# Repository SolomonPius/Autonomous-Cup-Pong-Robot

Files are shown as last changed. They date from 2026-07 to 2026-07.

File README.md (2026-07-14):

# Autonomous Cup Pong Robot

An autonomous turret robot that detects, aims at, and launches ping-pong balls into cups — built for MIE438 (Embedded Systems) at the University of Toronto.

**[Demo Video](https://www.youtube.com/watch?v=Q0vxaehKVus)**

Built by Solomon Pius, Abanoub Bashara, Roy Bou Abboud, and Yiyi Xu.

---

## Overview

The robot follows a sense-plan-act architecture: a rotating 1D LiDAR (TF-Luna) scans the playing field to find the closest cup, the ESP32 computes the required turret angle, and a servo-actuated turret aims and fires a ping-pong ball using dual flywheel motors and a feeder mechanism.

The project began as a full computer-vision-based aiming system (see [Project Proposal](docs/process/MIE438_Project_Proposal.pdf)) but was scoped down mid-project to a single-board, LiDAR-based design to fit the course timeline while preserving the core sense-plan-act architecture — full reasoning in the [Final Report](docs/process/MIE438_Final_Report.pdf).

**Final performance:**
- 100% cup detection rate
- ±2° angular accuracy
- Reliable shooting range up to 200cm

---

## Features

- **Perception:** TF-Luna LiDAR mounted co-axially with the turret barrel, scanning 5°–120° in 2° increments over I²C (400kHz) to find the minimum distance to a cup.
- **Aiming:** MG995 servo turret, slewed at a controlled max rate (2°/25ms) to avoid structural torque/instability.
- **Launch:** Dual brushless flywheel motors (L298N driver, 1kHz PWM) ramped to a fixed RPM, paired with a feeder motor (BTS7960 driver, 20kHz PWM) to advance the ball into the launcher.
- **Control:** Single ESP32-Wroom-32E running Arduino Framework C++ (PlatformIO), using a state machine (Scan → Aim → Fire → Done) to sequence the shooting cycle.
- **Custom hardware:** Fully custom 3D-printed mechanical structure, including a self-designed lazy susan bearing for turret rotation.

---

## System Architecture

```
[TF-Luna LiDAR] --I2C--> [ESP32] --PWM--> [Servo Turret]
                             |
                             +--PWM--> [Flywheel Motors (L298N)]
                             |
                             +--PWM--> [Feeder Motor (BTS7960)]
```

Full pinout and subsystem table in [docs/electrical/](docs/electrical/).

---

## Repo Structure

```
├── firmware/
│   ├── src/main.cpp          # Main control loop & state machine
│   └── tests/                # Per-peripheral bring-up test programs
│       ├── tfluna/
│       ├── servo/
│       ├── radar_scan/
│       ├── l298n/
│       ├── flywheel/
│       ├── hall_sensor/
│       ├── ir_beam/
│       └── all_motors/
│   └── tools/
│       └── radar_view.py     # Python visualizer for LiDAR polar scan
├── docs/
│   ├── electrical/            # Schematic, BOM, pinout diagram
│   ├── mechanical/             # CAD assembly, final assembly photos
│   ├── software/                # Architecture diagram, firmware flowchart
│   └── process/                  # Proposal, final report, performance metrics, instructor feedback
└── README.md
```

---

## Hardware

| Subsystem | Device | ESP32 Pin(s) | Protocol |
|---|---|---|---|
| LiDAR | TF-Luna (0x10) | SDA=GPIO21, SCL=GPIO22 | I²C @ 400kHz |
| Turret | MG995 servo | GPIO4 | 50Hz PWM (ESP32Servo) |
| Flywheel A | L298N EN_A/IN1/IN2 | 13/14/16 | 1kHz PWM (LEDC ch 8) |
| Flywheel B | L298N EN_B/IN3/IN4 | 27/17/23 | 1kHz PWM (LEDC ch 9) |
| Indexer | BTS7960 RPWM/LPWM/R_EN/L_EN | 18/19/25/26 | 20kHz PWM (LEDC ch 10) |

Power: 12V LiPo for motors, LM2596 buck converter to 5V for servo/LiDAR, 3.3V from ESP32 for remaining components.

**Note:** The ball feeder tube CAD was sourced from [Tylr-J42/XRP-Ping-Pong-Ball-Shooter](https://github.com/Tylr-J42/XRP-Ping-Pong-Ball-Shooter) and is not original work — all other mechanical parts were custom-designed in Onshape.

### CAD Files
 
- **Live/editable:** [Onshape Document](https://cad.onshape.com/documents/006694550e54c6535ae3a296/w/fde7019724d253a4cde574ab/e/71389e919a5da7285be2d17a) — full feature tree, editable, always reflects the latest version.
- **Static/portable:** [Final_CAD_Assembly](docs/mechanical/Final_CAD_Assembly.step) — exported STEP file, viewable in any CAD tool, kept as a backup in case the Onshape link ever changes or becomes inaccessible.
---

## Testing & Validation

Each peripheral was bring-up tested independently before full integration (see `firmware/tests/`):
- `tfluna` — I²C bring-up and distance accuracy
- `servo` — end-to-end MG995 sweep
- `radar_scan` — combined servo + LiDAR polar scan (visualized via `radar_view.py`)
- `l298n` / `flywheel` — flywheel driver activation
- `all_motors` — full firing sequence, end-to-end

---

## Known Limitations & Future Work

- Flywheel motors run at a fixed shared duty cycle — a closed-loop RPM control system (hall-effect sensor + PID) was designed but not completed due to hardware issues.
- The custom-printed turret bearing introduced some tilt/instability during rotation.
- An IR beam sensor for shot-state detection was attempted but never worked reliably in testing.
- Planned upgrades: 2D LiDAR (replacing the rotating scan), full autonomy-stack state machine, working IR beam integration.

Full reflection in the [Final Report](docs/process/MIE438_Final_Report.pdf).

---

## AI Usage Disclosure

In accordance with course guidelines: Claude and Claude Code were used for generating/refining inline code comments and documentation, and for debugging assistance (peripheral bring-up issues, sensor behavior interpretation). All architectural decisions, hardware design, firmware logic, and testing were performed by the team.

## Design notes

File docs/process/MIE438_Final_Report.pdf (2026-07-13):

# MIE438 Project Report: Autonomous Cup Pong Robot

### April 7, 2026

### Abanoub Bashara (1010010612) Solomon Pius (1009975127) Roy Bou Abboud (1009905462) Yiyi Xu (1009851402)

### Demo link: https://www.youtube.com/watch?v=Q0vxaehKVus

# Introduction & Project Evolution

The original project proposal outlined a five-phase plan to develop an autonomous cup pong robot capable of playing a perfect game without human intervention. Phases three to five focused on computer vision (CV) and user interface (UI) design. After receiving feedback on our proposal, we made the decision to eliminate the computer vision subsystem from the scope (see docs/process/Instructor_Feedback.md). The primary concern was integration complexity as well as course relevance. Developing a reliable vision pipeline and integrating it with a real-time embedded control stack introduced many points of failure and was far out of scope for this course’s content.

Instead of CV, we decided to use a 1D LiDAR (TF-Luna), which provides direct distance measurement to the cups. By mounting the LiDAR on the rotating base, we are able to scan the entire playing field. This pivot allowed us to preserve the core sense-plan-act architecture of the robot while also allowing the team to focus on the embedded problems: sensor integration, motor power & control, and communication protocols.

The revised project scope targets completion of Phase 1 (MVP – repeatable ball launch at fixed distance) and Phase 2 (LiDAR-enabled autonomous aiming and launch at a fixed distance). The final turret robot boasts a servo-actuated base to scan the playing field and aim the turret, a LiDAR subsystem that finds the closest cup using minimum distance, dual brushless motors that spin flywheels to a set RPM, and a feeder motor to push the ball into the launcher.

# Final System Architecture

The final system uses only a single ESP32 development board to consolidate all computation and real-time control (see docs/electrical/ESP32_Pinout_Diagram.pdf). This is a significant simplification from the original dual-platform architecture (Raspberry Pi + ESP32), which was proposed in the initial design. The elimination of CV also removed the need for a high-compute platform entirely. This also helped tighten integration between sensing and actuation since every signal is either generated or consumed directly by the ESP32. The final architecture follows a sense-plan-act paradigm (see docs/software/Software_Architecture.png and docs/software/Firmware_Flowchart.png).

For sensing, the TF-Luna sensor is mounted co-axially with the turret barrel to measure the cup distances and communicate with the ESP32 over I

2C (see firmware/src/main.cpp, line 123). After powering on the system, the robot begins by sweeping across 5 to 120 degrees of the playing field (and back) in 2-degree increments and logging the smallest measured distance. Each step is delayed by 120ms to gather a reading, and the communication over I

2C occurs at a very fast 400kHz frequency to ensure minimal latency. After an entire scan, the minimal distance to a cup and the angle at which it was found is passed as an input to other subsystems.

Next, the current version of our robot requires minimal planning. We had planned for a system that would use a full projectile model or interpolate distances to calculate the PWM (and hence speed) to reach a given cup, this could not be implemented due to faulty hardware. This would be a large improvement in future iterations if undertaken. Instead, the robot plans a servo rotation to the angle that recorded the shortest cup distance, and uses a fixed PWM for every shot (meaning shot distance was fixed as well) (see firmware/src/main.cpp, line 171-232).

For actuation, the ESP32 then commands the servo to slowly slew towards the selected angle at a max of 2 degrees per 25ms to avoid sudden movements (see firmware/src/main.cpp, line 137). This was needed as writing the angle to the servo directly would create a large torque, which could damage the structure or cause instability. After reaching the given angle, the ESP32 pushes PWM signals, which gradually increase into the flywheel motors via a L298N motor driver until the set value is reached. The flywheels first receive a PWM of 120/255 duty for 300ms to overcome the heavy load from the wheels and begin spinning. Then, the duty is dropped to 42/255 for 6 seconds to allow a proper spin-up, which is followed by a 150/255 duty to the feeder motor, which advances the ball into the launcher (see firmware/src/main.cpp, line 235-292).

Beyond that, the system is powered using a 12V LiPo battery for the motors, an LM2596 buck converter providing 5V to the servo & other peripherals, and the standard 3.3V output from the ESP32 for the remaining components.

# Hardware Design

The 3D printed subsystem can be found in docs/mechanical/Final_CAD_Assembly.obj. This shows the final assembly of our 3D printed parts. From the final assembly document, the ball feeder tube was the only part not designed by us. It was taken from a GitHub repository created by Tylr-J42 https://github.com/Tylr-J42/XRP-Ping-Pong-Ball-Shooter. The used file can be found in Ping Pong Ball Shooter v29.step. All other parts of the CAD were created using Onshape.

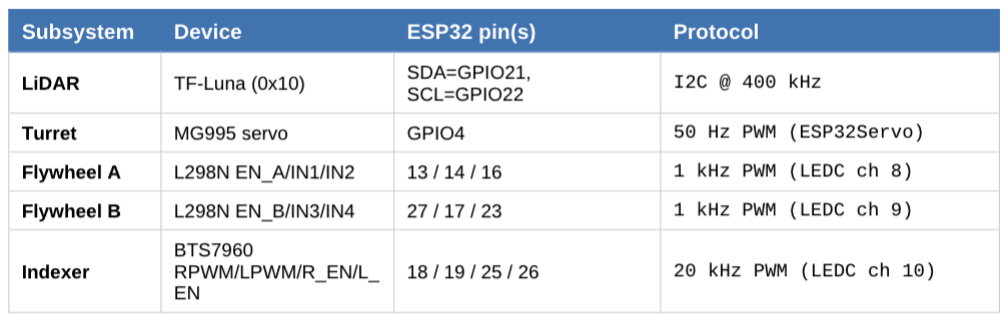
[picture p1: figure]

Table 1: Hardware Subsystem and ESP32 Connections

The core compute system is the ESP32-Wroom-32E running Arduino Framework C++ compiled through PlatformIO. Power is supplied from a 12V battery pack with a separate regulated 5V for the servo and TF-Luna, and 12V for the motor drivers.

The flywheels share the L298N and run at the same duty; we were not able to complete an RPM sensor and variable control system (see Reflection / Conclusion section) to address this. The BTS7960 drives the indexer because it has significantly higher current headroom for the stall current during ball-push. Running the indexer to 20 kHz kept the motor out of the audible whine range, while the L298N flywheels run at 1 kHz, which the L298N’s slower switching tolerates well.

A system schematic and full BOM are in docs/electrical/.

# Firmware Design

All firmware can be found in firmware/. The PlatformIO project also defines one bring-up environment per peripheral: TF-Luna, IR beam, hall sensor, limit switches, flywheel, servo, and indexing motor. Each is compiling a single test file in firmware/tests. These programs were how we validated each subsystem before integration, and they remain the authoritative reference for each peripheral’s wiring.

A firmware flowchart can be found in docs/software/Firmware_Flowchart.png

Use of ESP32 Peripherals
Course-relevant microcontroller features used:
- • I

2C (Wire) at 400 kHz, reading six bytes from TF-Luna register 0x00 per sample and extracting a little-endian 16-bit distance.
- • LEDC (ledcSetup / ledcAttachPin / ledcWrite) for three independent hardware PWM
- channels at different frequencies, the only way to run the BTS7960 at 20 kHz and the L298N at 1 kHz simultaneously without software-PWM jitter.
- • ESP32Servo (Arduino library on top of LEDC) for 50 Hz RC servo pulses at 500–2500 μs.
- • USB serial at 115 200 baud as both a human-readable log and a machine-readable CSV
- stream for offline polar plotting.

Libraries Used:
All developer-supplied libraries (Arduino core for ESP32, Wire, LEDC) are part of the Espressif Arduino framework, and per the course guidelines, do not require citation.
Third-party library: ESP32Servo - Kevin Harrington, John K. Bennett. https://github.com/madhephaestus/ESP32Servo

# Testing & Results

Each peripheral was validated independently using the test environments in firmware. firmware/test/tfluna verified I

2C bring-up and distance accuracy; firmware/test/servo swept the MG995 end-to-end;firmware/test/radar_scan validated the combined servo + LiDAR polar scan. The LiDAR polar scan was visualized by taking the LiDAR outputs, streaming them through serial to a Python program that visualized the output (see firmware/tools/radar_view.py). The servo then returns to the minimum distance measured by the LiDAR; firmware/test/l298n and firmware/test/flywheel validated the flywheel driver activation; and firmware/test/all_motors validated the full firing sequence end-to-end.

End-to-end performance metrics (see docs/process/Performance_Metrics.pdf)

- Cup detection rate: 100%
- Angular accuracy: +/- 2 degrees
- Maximum reliable shooting distance: 200cm

# Course Content Connection

This project required many MIE438 concepts to complete on both the hardware and firmware sides. The ESP32 was selected due to its breadth of GPIO pins (see docs/electrical/ESP32_Pinout_Diagram.pdf), strong compatibility with hardware requiring both 3.3V and 5V, and its flexibility for integrating course concepts under one hood. All inputs, outputs, control signals and some powering were all coordinated through the ESP32.

In order for our robot to find the minimum distance from itself to a cup, we combined the I

2C protocol
with macros to create the cup detection subsystem. The I

2C communication protocol was set up between the ESP32 and TF-Luna LiDAR, simplifying the transfer of data significantly and ensuring consistent readings for the robot to aim itself properly. A macro was used to combine two 8-bit (1 byte) signals read over I

2C into a single 16-bit value to quickly construct the signal needed for the robot to choose the best shooting angle (see firmware/src/main.cpp, line 39). Similarly, inline functions were used for actions that were repeated multiple times and required quicker execution, such as setting the duty cycle for the flywheel or stopping all the motors at once (see firmware/src/main.cpp, line 107-118).

Additionally, the concept of pulse-width-modulation (PWM) was used in conjunction with motor drivers to control the three motors on our system: 1) the two flywheel motors and 2) the feeder motor. Varying PWM was initially used as a testing strategy to qualitatively determine the range of values that yield a feasible launch distance of the ball (see docs/mechanical/Final_Assembly.png). Then, PWM signals were generated from the ESP32 and delivered to the appropriate motors via both our dual-channel motor drivers. This concept was important to our system, as we were building a control loop that used RPM readings to adjust PWM in order to eliminate any variance between both motors (however, this system was never implemented due to faulty hardware).

Furthermore, we made use of a state machine to encode the robot’s different stages during a shooting cycle. The three states were Scan, Aim, Fire, and Done. This greatly helped our system by breaking down phases within the sense-plan-act paradigm and allowing for easy debugging and readability. For example, timing the flywheel and feeder motors with the servo was much easier once we implemented a state machine that distinguishes between both phases (see firmware/src/main.cpp, line 235-292).

Finally, two additional PID controllers were planned for the system and would be the next improvements that incorporate course concepts. The first one would be a DIY RPM sensor using a magnet and hall effect sensor on the flywheel (see firmware/tests/hall_sensor/main.cpp). This system would take in RPM, use a precalculated “RPM vs Distance Travelled by Ball” chart to determine a PWM value for a required cup distance, and adjust accordingly using a tuned PID controller. Similarly, the built-in encoders of the feeder motor would be fed as an input to a second tuned PID, which would control the total rotation of the feeder, increasing consistency between shots.

# Reflection & Conclusion

The two most consequential engineering design decisions we made for this project were the pivot away from computer vision and the consolidation to a single ESP32 platform. We believe both decisions were correct. Eliminating the CV pipeline allowed us to focus on the actual embedded systems work, such as sensor integration, hardware assembly, design testing, and firmware architecture. The TF-Luna was a clean replacement that fit naturally with the ESP32 stack over I

2C.

The most significant issues we encountered that limited our robot’s capabilities were all related to mechanical or hardware rather than firmware. Firstly, the custom ball bearing we created for the rotating base caused turret tilting and, at times, instability during rotation (see docs/mechanical/Final_Assembly.png), creating a launch error that could never be reduced. Secondly, only 1 out of 2 hall sensors was proven to be effective, and there was no structurally sound way of attaching the neoprene magnets to the flywheel at high RPMs, hence abandoning the PID-controlled PWM for the motors was required. Thirdly, the infrared beam sensor we wanted to implement on the robot to determine the current state of the ball launch never worked during testing, and was therefore removed from the system (see firmware/tests/ir_beam/main.cpp). Finally, the PID-controlled feeder motor was also never implemented due to hardware issues related to its wiring, which unfortunately meant no physical control loops within our system. In the future, fixing these issues would be the biggest way of improving the robot’s performance considerably. Beyond that, other upgrades that would strengthen our robot include using a 2D lidar as opposed to the servo spinning base, implementing a fully-fledged state machine for the entire autonomy stack, or successfully fitting an infrared beam to detect when the ball is launched.

In conclusion, we worked around our original ambitious goal and created a successful embedded system centred around a single ESP32 that correctly shot ping-pong balls into cups.

# AI Usage Statement

In accordance with course guidelines, we disclose the use of AI tools during this project. Anthropic's Claude and Claude Code were used in two limited capacities: generating and refining inline code comments and documentation within the firmware source files, and assisting with debugging after firmware development, including diagnosing peripheral bring-up issues and interpreting unexpected sensor behaviour. All architectural decisions, hardware design, firmware logic, and testing were performed by the team. AI-generated suggestions were reviewed, validated, and modified by team members before being incorporated into the final codebase.

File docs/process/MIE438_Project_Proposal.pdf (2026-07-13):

## MIE438 Project Proposal: Autonomous Cup Pong Robot

### January 19, 2026

### Abanoub Bashara (1010010612) Solomon Pius (1009975127) Roy Bou Abboud (1009905462) Yiyi Xu (1009851402)

1. Problem Overview & Solution Scope 1.1 Proposed Project Timeline
2. High-Level System Overview
2.1 Overall System Architecture
2.2 Perception Subsystem
2.3 Computational & Control Subsystem 2.4 Actuation Subsystem
3. Hardware (Mechanical / Electrical) Details
4. Software / Controls / UI Details
5. Conclusion

## 1. Problem Overview & Solution Scope

Cup Pong (otherwise known as Beer Pong) is a social game consisting of two teams taking turns throwing a ping pong ball into the opposition’s cups. Ten cups are placed on both ends of the table, typically in a pyramid formation, with teams standing behind their respective set of cups. Each team, composed of 1-2 players, receives two attempts at sinking a ping pong ball across the table before the turns switch. If a ball is sunk into a cup, that cup is removed from the game, and in order to win, a team must sink a ball into all the opposition's cups. Additionally, if a team sinks both of their shots within an attempt (ie. they didn’t miss), they receive an additional two shots as a reward, known as balls back, with no limit to how many times this can be done. Hence, if a team receives balls back and continually hits their two shots, they can win the game in a single turn, known as a perfect game.

The objective of our project is to develop an Autonomous Cup Pong Robot capable of playing a perfect game without human intervention. An overview of the robot’s capabilities includes:
1. Detecting cup geometry and distance from one end of the table
2. Pivoting its launcher in the direction of a desired cup
3. Calculating the required launch speed of the ping pong ball
4. Launching the ball and sinking it into a cup
5. Repeating steps 1-4 until the robot achieves a perfect game

Many game mechanics are beyond the scope of the robot yet still crucial to the game’s playability. Human interaction to ensure a smooth game is required in the following ways:
- The robot’s storage tank must be manually filled with ping pong balls
- Once a cup is eliminated, a human will remove the cup off the table
- After a shot, the robot should standby until it receives the green light from a human to shoot again. This can be phased out in improved designs
- If the robot misses, a human will manually place it in standby after its attempt

### 1.1 Proposed Project Timeline

Phase 1: Minimum Viable Product (MVP)
A single cup is placed at a fixed, known distance directly in front of the robot. This phase will verify that the core turret and launching mechanisms work. This phase will be considered complete once the system can demonstrate repeatable ball release with controllable velocity and consistent projectile motion.

Phase 2: Controlled Autonomy
Again, a single cup is placed, but now at a random location on the table. The coordinates will be manually provided to the robot. The robot autonomously rotates its base to align with the target and computes the required launch speed to successfully sink the ball. This phase must demonstrate closed-loop control over aiming and velocity.

Phase 3: Vision-Based Target Detection
Again, a single cup is placed at a random location on the table. The robot must now use its camera-based perception to detect the position of the cup and extract the coordinates in order to aim and sink the ball.

Phase 4: Full Game Automation (Perfect Game)
The robot sequentially targets and eliminates all cups on the table, with the only human intervention being cup removal and ball reloading. This phase is complete once the fully autonomous pipeline can consistently win perfect games.

Phase 5: User Experience & Taunting
This phase adds a simple interface to switch between manual cup selection and fully autonomous gameplay. Optionally, audio and/or visual taunting may be implemented.

## 2. High-Level System Overview

The robot is designed in a modular manner, as demonstrated in the distinct phases outlined in section
1.1. At a high level, the system follows a sense-plan-act architecture: visual information about the environment is processed to determine target locations, a ball trajectory is computed, and the mechanical subsystems execute the shot.

### 2.1 Overall System Architecture

The system is composed of three interacting subsystems (see figure 1 in the appendix):
1. Perception Subsystem (Phase 3+): identifies cup locations on the table
2. Computation & Control Subsystem (Phase 2+): computes aiming and launch parameters
3. Actuation Subsystem (Phase 1+): physically loads, aims, and launches the ball
This separation allows for the development and testing of subsystems before full system integration.

### 2.2 Perception Subsystem

A camera is mounted on a stationary base on top of the robot and captures a 2D image of the playing field. This image is processed by computer vision algorithms to detect cup geometry and estimate the coordinates of each cup relative to the robot. These algorithms will either run on an external remote laptop or a Raspberry Pi to decouple from time-sensitive computation (next section). We also suspect that a dual-chip board such as the Arduino Uno Q might be of use in this application.

### 2.3 Computational & Control Subsystem

Based on the coordinates, this system computes the required turret rotation angle and launch speed using projectile motion models. A low-level language (e.g., C++) running on an ESP-based microcontroller or similar executes real-time control tasks, including motor commands, timing and sequencing.

### 2.4 Actuation Subsystem

This system consists of a Nerf-style motorized launcher to provide ball velocity, a secondary actuator (servo or solenoid) for ball loading, and a rotating base or turret for horizontal aiming. The motorized launchers spin two flywheels at a set speed to launch the ball. Upon receiving control commands, the robot aligns itself with the target, adjusts launcher speed, feeds a ball, and fires.

## 3. Hardware (Mechanical / Electrical) Details

### 3.1 Hardware Overview

The design features a fixed base with a camera attached via a vertical mast; the shooter is mounted on top of the base and rotates the turret independently of the base (See figure 2 in the appendix). Upon activation, a fixed camera takes a picture of the cup field (assuming standard camera placement and lighting). The compute unit then processes the frame to find cup coordinates and calculates the required turret angle and flywheel RPM to reach the target cup. These metrics are then fed to the embedded controller, which rotates the turret, ramps the flywheel to the command RPM and activates the loader to feed a ball into the spinning wheels for launch.

### 3.2 Actuation + Mechanical Design

The system utilizes 3 actuators. (1) Two Nerf-style motors that spin flywheels to a given RPM for launch. (2) a turret motor to rotate the shooter heading, (3) a feeder motor driving a pinion mechanism to push one ball at a time into the spinning flywheel. The flywheel RPM will be controlled by varying motor drive power, while the turret and feeder move at a slow, consistent rate to avoid structural stress. The vertical shooting angle of the turret will be fixed at 50-60 degrees, striking a good balance between maximizing shot distance and ball height as well as minimizing drag.

### 3.3 Sensors + I/O Requirements

The system's primary sensor is a mounted camera that captures an image on user command. That image is then processed on a Raspberry Pi or remote Laptop and outputs setpoints to the MCU over USB serial (Target turret angle & Flywheel RPM). Table 1 in the appendix shows estimates on the quantitative I/O analysis.

### 3.4 Compute + Embedded Platform

The system uses a Raspberry Pi 4 Model B or Remote PC for camera capture, vision, trajectory/RPM/angle calculation and an ESP32 for real-time actuation (turret servo control, flywheel RPM command generation, feeder sequencing and standby logic). Since the ESP32 is 3.3V logic, if any hardware requires 5V signalling, level shifting may be required. Power will come from a wall adapter with separate regulated rails for logic, 5V for Pi, 3.3V for ESP32, and motors as required.

### 3.5 Power + Key Components/BOM

The system will be powered via a wall adapter that steps down to the required rails for the ESP32, servos, and flywheel motors. Safety hardware will include a power switch plus fuse, and a fuse holder in line with the supply. Current BOM can be found in the appendix.

## 4. Software / Controls / UI Details

The software required for this project goes beyond the scope of this course, but we believe proper implementation is needed to manifest our vision of what a fully autonomous cup pong robot should achieve.

### 4.1 Vision

As mentioned before, the software is responsible for producing control commands for where the shooter needs to aim. We first need to pre-process the image by removing the tilt effect from the camera, and then extracting the location of the cups. To achieve this, there are 2 methods we can explore. The first method is using existing libraries for computer vision, such as OpenCV/cv2 in Python, and using least squares regression to fit circles on the rims of the cups. The center of the circles should be the coordinate of the cup and thus the shooter should aim there. A technique that can make this approach more effective is to apply some sort of retroreflective paint to the rim of the cups, and using a camera that can pick up said retroreflective paint. An alternative method, which might yield better results, is to manually train our own vision model on labelled data of images of shots. This will be more tedious to do but might yield better results if we are unable to fit OpenCV in our use case.

### 4.2 Controls

Once the coordinates of the cups are determined, we can select 1 cup to shoot at first. There are again 2 ways to convert coordinates to turret angle and shooter RPM. We can either solve for them analytically using inverse kinematics, which in theory should work 100% of the time. However, under real conditions with non-negligible drag and spin on the ping pong balls, idealized assumptions might not hold up. A different method is to manually find pivot angle + shooter RPM combos by testing different shots, and then interpolating those points for all the cup locations.

The turret motor should have an encoder, so we’re able to use a closed loop control such as PID to get it to its desired location. For the flywheel motors, we can use an RPM sensor to achieve closed loop speed control, with the control input being the PWM duty cycle. For any known target distance, the system determines a desired motor RPM, and the PWM signals are adjusted using the RPM sensor to achieve this desired value before the ball is launched.

### 4.3 UI

There needs to be some way for us to interact with the robot once it starts playing the game. Most likely we will have a simple push button to allow the robot to start shooting once it's been reloaded and between shots.

If the robot is able to consistently win games, we can add an LCD display to personify the robot and add a competitive flair. It can taunt the enemy when it makes shots and emote as its shooting. Alternatively it can be used as a status light, showing us what state the robot is in (spinning up shooter, aiming, processing, etc).

## 5. Conclusion

Overall, we believe this embedded system design is feasible under the scope of this course and we are highly interested in pursuing this project. We consider achieving Phase 2 (Controlled Autonomy) a complete embedded systems project, with subsequent phases adding additional functionalities that greatly increase the system’s performance. It is important to note that 3D printed structural and mechanical components such as the base, gears, etc are not part of the embedded systems design work we are planning to pursue, and hence, we will be using pre-existing models found on the internet. Additionally, we plan on always testing and demonstrating our system in stable environments with good lighting, mitigating unintended factors (e.g. occlusions) that may decrease the robot’s performance. Finally, in terms of teaching team feedback, what would help us the most is insight on whether using a Raspberry Pi, Arduino Uno Q, or remote PC as a replacement or in combination with an ESP32 DevBoard are admissible options for the course and this project.

## 6. Appendix

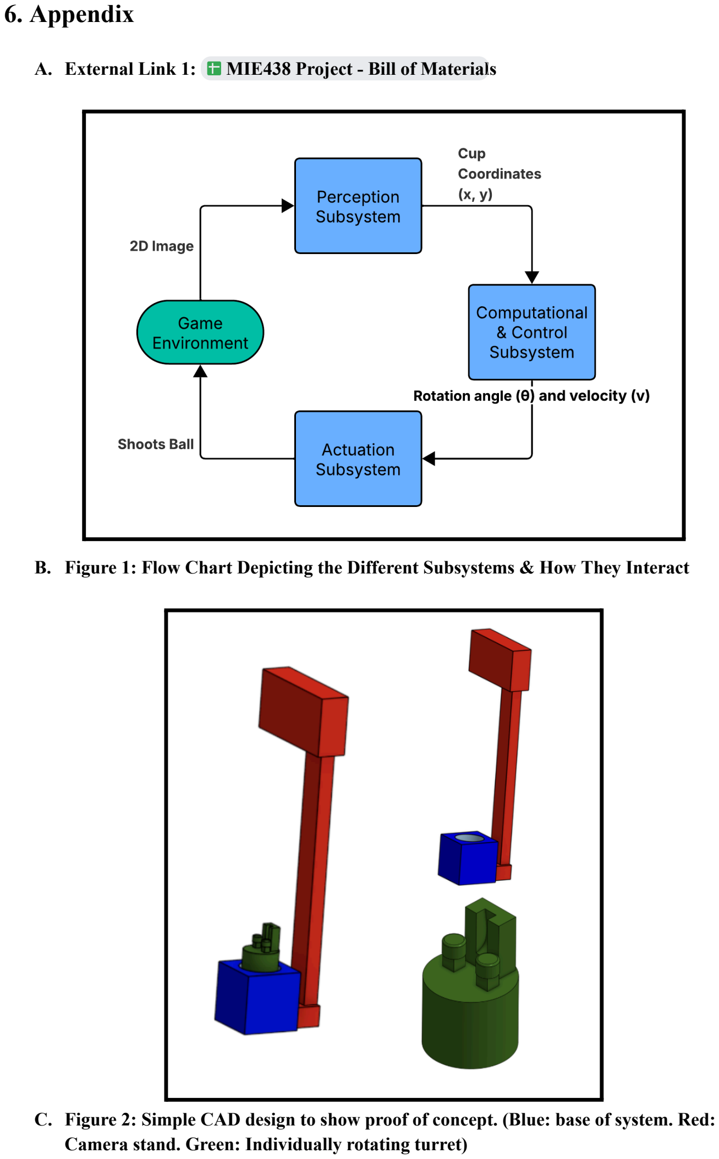
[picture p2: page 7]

A. External Link 1: MIE438 Project - Bill of Materials (https://docs.google.com/spreadsheets/d/1_pdvrkftF5BO4UQJaOoq0thF5PodlNcQAFAqRodngs0/edit?gid=0#gid=0)
B. Figure 1: Flow Chart Depicting the Different Subsystems & How They Interact
C. Figure 2: Simple CAD design to show proof of concept. (Blue: base of system. Red: Camera stand. Green: Individually rotating turret)

Signal | Type | Where | Estimated range/requirement
Camera frame | USB/CSI video | Pi | 1280×720 (or 640×480) single-frame capture; needs consistent lighting for detection
User ‘shoot’ trigger | Digital GPIO | Pi | Button input (0/1), debounced (~20–50 ms)
Turret angle (tracked) | Software state | MCU | 0–180° (or ±90°), updated from last command; resolution target ~1–2°
Setpoints (angle, RPM, fire) | USB serial | Pi → MCU | ~5–10 Hz command updates; target end-to-end latency < ~250 ms
Flywheel command | PWM(to motor driver) | MCU → driver | RPM setpoint ~0–20,000 RPM (estimate), resolution ~100–250 RPM
Turret motor command | Step/Dir or PWM | MCU → driver | Slow slew target ~10–30 °/s (estimate)
Feeder command | PWM + dir (or timed on/off | MCU → driver | One-ball feed cycle ~0.5–1.5 s (estimate), return-to-zero after shot
D. Table 1: Hardware I/O Map

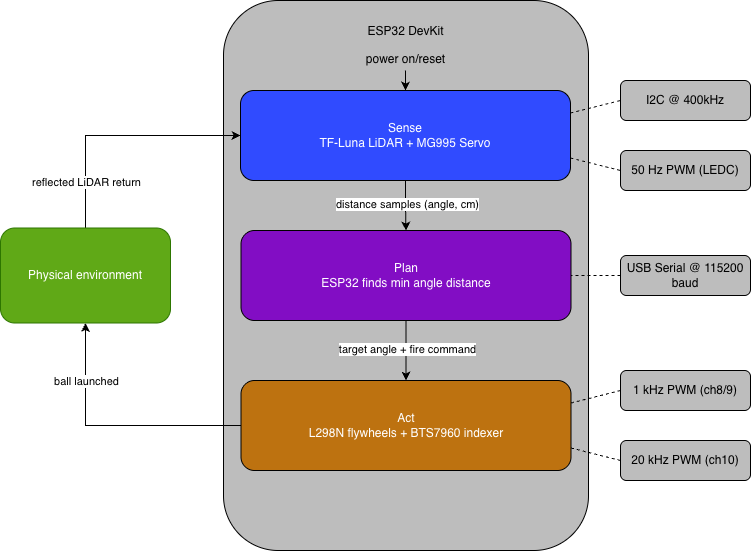
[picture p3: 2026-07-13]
docs/software/System_Architecture.png

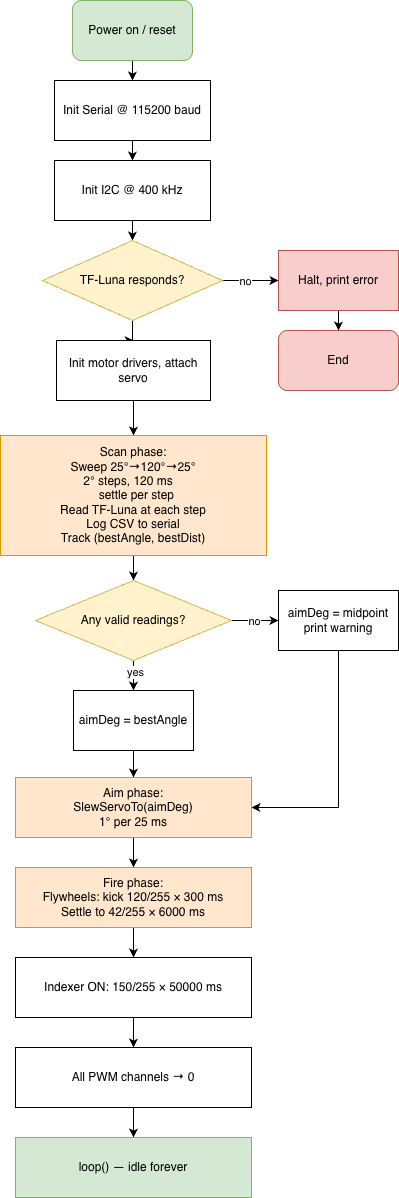
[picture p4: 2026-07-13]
docs/software/Firmware_Flowchart.png

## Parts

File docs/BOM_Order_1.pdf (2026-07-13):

Final List:
- 2x Flywheel motors
- 775 Brushed DC Motors
- https://www.amazon.ca/dp/B0BB2V8PNK/ref=olp-opf-redir?aod=1
- 1x Base motor
- 130 RPM Motor (Loaned)
- 1x Servo - Rack & Pinion Ball Feeder
- MG995 Servo (Loaned)
- 3x Motor Drivers OR 1x Dual + 1x Single Motor Drivers
- DRV8825PWP Single
- https://www.digikey.ca/en/products/detail/texas-instruments/DRV8825PWP/2676775 (https://www.digikey.ca/en/products/detail/texas-instruments/DRV8825PWP/2676775)
- TB6612FNG,C,8,EL
- https://www.digikey.ca/en/products/detail/toshiba-semiconductor-and-storage/TB6612FNG-C-8-EL/1730070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 4iAugL5A (https://www.digikey.ca/en/products/detail/toshiba-semiconductor-and-storage/TB6612FNG-C-8-EL/1730070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)
- 1x Infrared Sensor - Ball Detection
- https://www.mouser.ca/new/dfrobot/dfrobot-sen0503-ir-break-beam-sensor/
- 1x Lidar Sensor
- TF-Luna (Loaned)
- 1x Ultrasonic Sensor
- HC-SR04 (Loaned)
- 1x Power Switch (Rocker)
- https://www.digikey.ca/en/products/detail/e-switch/RA1113112R/3778055
- 1x Buck Converter
- https://www.digikey.ca/en/products/detail/texas-instruments/TPS51388VABR/25811453 (https://www.digikey.ca/en/products/detail/texas-instruments/TPS51388VABR/25811453)
- 1x Breakout Board
- https://www.digikey.ca/en/products/detail/adafruit-industries-llc/4090/9951930
- 2x Limit Switch
- https://www.digikey.ca/en/products/detail/e-switch/SS0750301F040P1A/2639 078 (https://www.digikey.ca/en/products/detail/e-switch/SS0750301F040P1A/2639078)
- 2x Hall Sensors
- https://www.digikey.ca/en/products/detail/infineon-technologies/TLE4906LHALA1/954435 (https://www.digikey.ca/en/products/detail/infineon-technologies/TLE4906LHALA1/954435)
- 4x Pushbuttons
- https://www.digikey.ca/en/products/detail/same-sky-formerly-cui-devices-/TS02-66-55-BK-160-LCR-D/15634374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 (https://www.digikey.ca/en/products/detail/same-sky-formerly-cui-devices-/TS02-66-55-BK-160-LCR-D/15634374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)
Misc:
- Jumper Wires
- Breadboard
- M3 Screw Kit (Loaned)
- Small Magnets (Roy)
- Push Button
- Lazy Susan Bearing

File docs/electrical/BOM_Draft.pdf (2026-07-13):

NOTE: Structural items will be 3D printed for cost and time effectiveness. This includes parts such as the structural body, gears, rack, etc. Items such as fasteners and screws for assembly are not included in this BOM.

COMPUTE & CONNECTION
ITEM | QUANTITY | COST (per unit) WEBSITE | NOTES
ESP32 DevKit V1 | 1 | 0$ | N/A | Provided by teaching team
OV2640 Camera Module | 1 | 1-25$ | TBD
Breadboard | 1 | 0$ | N/A | Easily rented
Jumper Wires + Connectors | As Needed | 0$ | N/A | Myfab scrab bin
Fuses + Fuse Holder | 1 | 1-5$ | TBD | Safety Precaution

ACTUATION & CONTROL
ITEM | QUANTITY | COST WEBSITE | NOTES
MG90S Servo | 2 | 1-10$ | TBD | 1 for pivoting base, 1 for driving pinion back and forth
Nerf Blaster Motors | 2 | 13-14$ | https://outofdarts.com/collections/motors-2019 | These motors would be ideal for speed, but other motors are also acceptable
Flywheels (Rubber) | 2 | 10-25$ | https://www.studica.ca/en/2inch-compliant-wheel-12-inch-hex-40-durometer-orange | Standard wheels may be used as an alternative
TB6612FNG (Dual) Motor Driver | 1 | 3-25$ | TBD
Buck Converter | 1 | 12-20$ | TBD | Step down input voltage from wall / laptop charger
Limit Switch | 1 | 1-3$ | TBD | Adds a reference to rack and pinion system
Power Switch | 1 | 1-2$ | TBD
RPM Sensor | 1 | 5-20$ | TBD | Closed looop control of flywheel speeds via PWM
INITIAL ESTIMATED COST (lower bound): | 48-149$

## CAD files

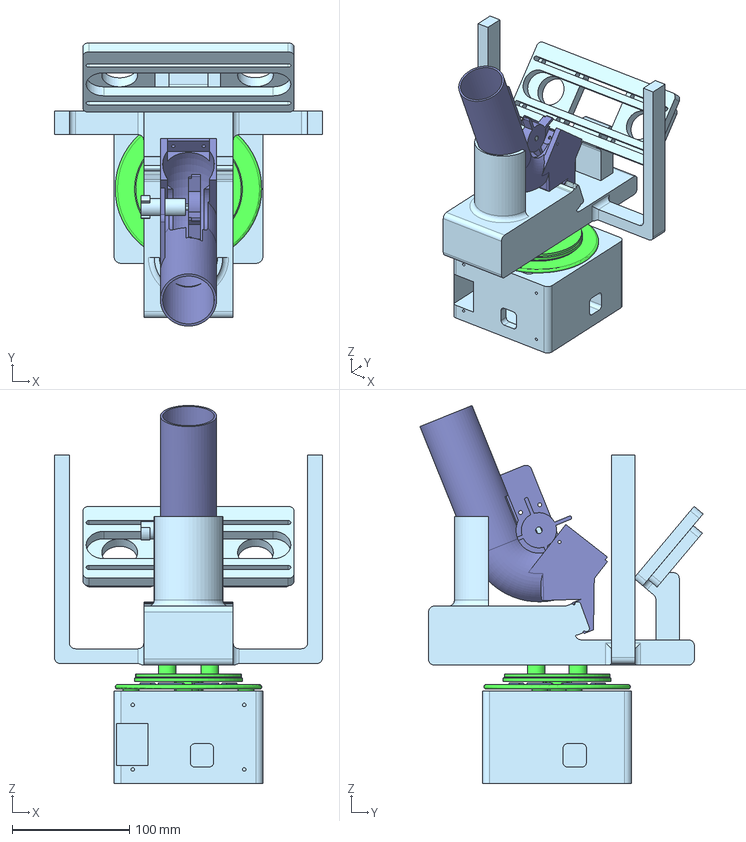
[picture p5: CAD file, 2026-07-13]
docs/mechanical/Final_CAD_Assembly.step
228.6 x 241.5 x 322.3 mm
Feeder Roller
retainer
Container Tube

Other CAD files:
docs/mechanical/Final_CAD_Assembly.obj

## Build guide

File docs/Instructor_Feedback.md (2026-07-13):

Level of detail in proposal: Meets expectations. The proposal addresses all requested points and presents a clear plan of progression with fall-back options.

Scope of proposal: The general scope encompasses basic motor control, possibly extended using computer vision to close the position loop. In terms of embedded topics, you may find this a bit light - not much communication protocols, MCU features used, etc., just some basic position control of motors. Consider finding some add-ons that use more MCU features or other peripherals (UI, A/V feedback, etc.). Also, consider that in embedded applications computer vision tends to be very challenging and high integration risk if done on the embedded platform, but doing it on an external platform isn't strongly linked to course content. So, avoid making this central past Phase 3 and consider what was mentioned above about scope.

Microcontroller selection: Using ESP32 and/or the Pi is reasonable, but more detail on the MCU selection (pinning, feature usage, etc.) would allow us to comment more specifically. Parts of section 3 cover this, but more detail would be appreciated.

System architecture: An architecture diagram would be helpful to better show the integration of peripherals, hardware, firmware, and mechanical components. The provided CAD and BoM helps in this regard. Overall no major concerns about the purchase list, but as above a more detailed/specific BoM would let us comment more specifically.

Overall embedded difficulty: Low, exlcuding vision integration - some basic motor control and comms tasks. No particular individual concern or integration concern, but see prior comments on the CV aspect.

Overall mechanical difficulty: Low, but don't expect the launcher to function nearly as repeatedly as you might expect. Compatible with RP methods/3D printing, so low risk for proof-of-concept regardless.

Other Notes: Good proposal and fun topic, well done.

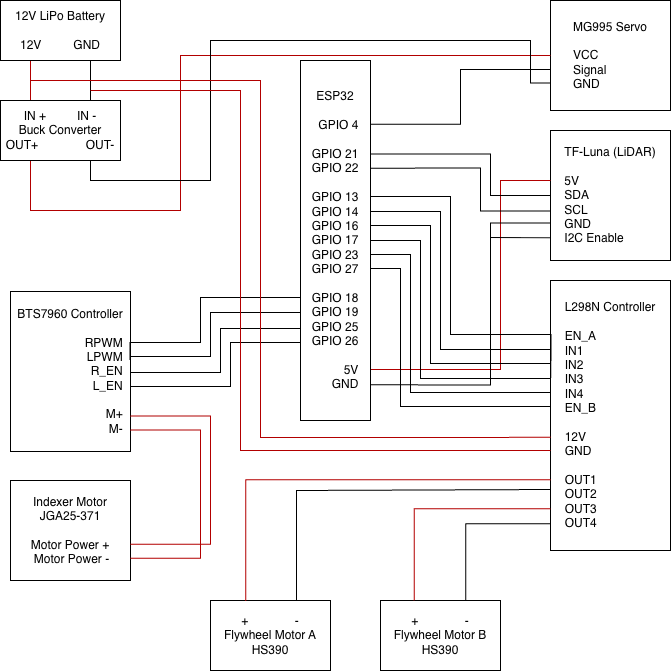
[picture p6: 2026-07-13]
docs/electrical/Wiring_Diagram.png

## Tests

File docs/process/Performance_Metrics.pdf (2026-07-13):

Metric | Accuracy (Trials) | Accuracy (Percent) Constraint | | Criteria
Cup Detection Rate | 20/20 | 100% | No less than 99% | The more the better
Angular Accuracy | 1.963 degress (avg.) | - | No more than 3 degrees | The less the better
Maximum Reliable Shooting Distance | ~200cm | - | No less than 150cm | The more the better
| Angular Trials: | | Maximum Reliable Shooting Distance
1 | 1.952 | 1 | ~210cm
2 | 2.086 | 2 | ~200cm
3 | 1.927 | 3 | ~200cm
4 | 1.934 | 4 | ~190cm
5 | 1.916 | 5 | ~200cm
AVG | 1.963 | AVG | ~200cm

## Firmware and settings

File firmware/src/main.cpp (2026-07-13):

// Pong Robot – main firmware (Scan → Aim → Fire)
//
// Flash:   pio run -e esp32dev -t upload
// Monitor: pio device monitor          (115200 baud)
//
// Sequence (state machine driven from loop()):
//   SCAN  – Sweep servo 25°→120° and back, reading TF-Luna at every step.
//           Print angle and distance for each sample. Track the closest
//           valid reading as the target.
//   AIM   – Rotate servo to the best angle (or midpoint if no valid samples).
//   FIRE  – Flywheel kick-start → settle to FLY_DUTY → indexer ON → stop all.
//   DONE  – Terminal state; all motors off.
//
// Wiring:
//   Servo            → GPIO4   (50 Hz PWM via LEDC)
//   TF-Luna SDA/SCL  → GPIO21 / GPIO22  (I2C, 400 kHz fast-mode)
//   L298N (flywheels):
//     EN_A=GPIO13 IN1=GPIO14 IN2=GPIO16  (Motor A)
//     EN_B=GPIO27 IN3=GPIO17 IN4=GPIO23  (Motor B)
//   BTS7960 (indexer):
//     RPWM=GPIO18 LPWM=GPIO19 R_EN=GPIO25 L_EN=GPIO26
//
// Course concepts demonstrated:
//   - State machine       → RobotState enum + switch in loop()
//   - I2C protocol        → TF-Luna sensor reads via Wire library
//   - PWM                 → LEDC peripheral for motor speed + servo position
//   - Macros              → BYTES_TO_U16 (little-endian byte reconstruction)
//   - Inline functions    → setFlywheelDuty(), stopAllMotors()
//   - Code reuse          → lunaReadCm(), slewServoTo(), sampleAt() subroutines
//   - constexpr constants → compile-time pin/config definitions (zero RAM cost)
//   - Loops & branches    → sweep loops, aim decision logic

#include <Arduino.h>
#include <ESP32Servo.h>
#include <Wire.h>

// ── Macros ──────────────────────────────────────────────────────────────────
// Reconstruct a little-endian 16-bit value from two bytes (Week 2: Numbering Systems)
#define BYTES_TO_U16(lo, hi)  ((uint16_t)(lo) | ((uint16_t)(hi) << 8))

// ── Servo / LiDAR pins ───────────────────────────────────────────────────────
static constexpr int PIN_SERVO = 4;
static constexpr int PIN_SDA   = 21;
static constexpr int PIN_SCL   = 22;

// ── TF-Luna I2C ──────────────────────────────────────────────────────────────
static constexpr uint8_t TFLUNA_ADDR = 0x10;
static constexpr uint8_t REG_DIST_L  = 0x00;

// ── Sweep config ─────────────────────────────────────────────────────────────
static constexpr int SWEEP_MIN_DEG  = 25;
static constexpr int SWEEP_MAX_DEG  = 120;
static constexpr int SWEEP_STEP_DEG = 2;
static constexpr int SETTLE_MS      = 120;   // servo settling time per step
static constexpr int SCAN_CYCLES    = 1;     // number of out-and-back sweeps

// ── Slow-slew config (used when rotating to target after scan) ───────────────
static constexpr int SLEW_STEP_DEG = 1;       // degrees per step
static constexpr int SLEW_STEP_MS  = 25;      // delay between steps
// 1°/25 ms → full 95° range takes ~2.4 s, smooth motion

static int currentServoDeg = 0;               // tracks last commanded angle

// ── L298N pins (flywheels) ───────────────────────────────────────────────────
static constexpr int PIN_EN_A = 13;
static constexpr int PIN_IN1  = 14;
static constexpr int PIN_IN2  = 16;
static constexpr int PIN_IN3  = 17;
static constexpr int PIN_IN4  = 23;
static constexpr int PIN_EN_B = 27;

// ── BTS7960 pins (indexer) ───────────────────────────────────────────────────
static constexpr int PIN_IDX_RPWM = 18;
static constexpr int PIN_IDX_LPWM = 19;
static constexpr int PIN_IDX_R_EN = 25;
static constexpr int PIN_IDX_L_EN = 26;

// ── PWM config ───────────────────────────────────────────────────────────────
// NOTE: ESP32Servo grabs LEDC channels from the pool starting at 0, so we
// reserve high-numbered channels (different timer group) to avoid ever
// having ledcSetup() clobber the servo's PWM frequency.
static constexpr int LEDC_CH_ENA   = 8;   // L298N Motor A
static constexpr int LEDC_CH_ENB   = 9;   // L298N Motor B
static constexpr int LEDC_CH_IDX   = 10;  // BTS7960 indexer

static constexpr int L298N_FREQ_HZ = 1000;
static constexpr int BTS_FREQ_HZ   = 20000;
static constexpr int PWM_RES_BITS  = 8;

static constexpr uint8_t FLY_KICK_DUTY = 120;  // kick-start duty
static constexpr uint8_t FLY_DUTY      = 42;   // settled duty (~20%)
static constexpr uint8_t IDX_DUTY      = 150;
static constexpr int     FLY_KICK_MS   = 300;
static constexpr int     FLY_SETTLE_MS = 6000;
static constexpr int     IDX_SPIN_MS   = 50000;

static Servo servo;

// ── State machine (Week 12: State Machines) ─────────────────────────────────
enum class RobotState { SCAN, AIM, FIRE, DONE };
static RobotState state = RobotState::SCAN;

// Scan results persisted across states
static int bestAngle = -1;
static int bestDist  = INT_MAX;

// ── Inline helper functions (Week 7: Compilation & Optimization) ────────────
// inline avoids function-call overhead while keeping the code DRY.

static inline void setFlywheelDuty(uint8_t duty) {
    ledcWrite(LEDC_CH_ENA, duty);
    ledcWrite(LEDC_CH_ENB, duty);
}

static inline void stopAllMotors() {
    setFlywheelDuty(0);
    ledcWrite(LEDC_CH_IDX, 0);
}

// ── Subroutines (Week 6: Code Reuse and Subroutines) ────────────────────────

// Read distance from TF-Luna in cm. Returns -1 on error.
static int lunaReadCm() {
    Wire.beginTransmission(TFLUNA_ADDR);
    Wire.write(REG_DIST_L);
    if (Wire.endTransmission(false) != 0) return -1;
    if (Wire.requestFrom((uint8_t)TFLUNA_ADDR, (uint8_t)6) != 6) return -1;

    uint8_t buf[6];
    for (int i = 0; i < 6; i++) buf[i] = Wire.read();

    return BYTES_TO_U16(buf[0], buf[1]);
}

// Slew the servo from currentServoDeg to targetDeg in small steps so the
// turret doesn't jerk. Blocks until done. Updates currentServoDeg.
static void slewServoTo(int targetDeg) {
    int step = (targetDeg > currentServoDeg) ? SLEW_STEP_DEG : -SLEW_STEP_DEG;
    while (currentServoDeg != targetDeg) {
        int next = currentServoDeg + step;
        // Clamp on last step if we'd overshoot
        if ((step > 0 && next > targetDeg) || (step < 0 && next < targetDeg)) {
            next = targetDeg;
        }
        servo.write(next);
        currentServoDeg = next;
        delay(SLEW_STEP_MS);
    }
}

// Move servo to deg, settle, then sample LiDAR once and track best.
// Updates bestAngle / bestDist in place.
static void sampleAt(int deg, int &bestAngle, int &bestDist) {
    servo.write(deg);
    currentServoDeg = deg;
    delay(SETTLE_MS);

    int dist = lunaReadCm();
    if (dist > 0) {
        Serial.printf("angle=%3d°  dist=%4d cm\n", deg, dist);
        if (dist < bestDist) {
            bestDist  = dist;
            bestAngle = deg;
        }
    } else {
        Serial.printf("angle=%3d°  dist=  -- cm  (read error)\n", deg);
    }
}

// ── Hardware initialisation (runs once) ─────────────────────────────────────
void setup() {
    Serial.begin(115200);
    delay(500);

    Serial.println("─────────────────────────────────────");
    Serial.println("  Pong Robot: scan → aim → fire");
    Serial.println("─────────────────────────────────────");

    // ── I2C + TF-Luna ────────────────────────────────────────────────────────
    Wire.begin(PIN_SDA, PIN_SCL);
    Wire.setClock(400000);
    Wire.beginTransmission(TFLUNA_ADDR);
    if (Wire.endTransmission() != 0) {
        Serial.println("ERROR: TF-Luna not responding.");
        while (true) delay(1000);
    }
    Serial.println("TF-Luna OK.");

    // ── L298N flywheel setup (idle) ──────────────────────────────────────────
    // IMPORTANT: initialize motor PWM BEFORE servo.attach() so we cannot
    // accidentally reconfigure a LEDC channel the servo library has already
    // claimed. Combined with the high channel numbers (8/9/10), this keeps
    // the 50 Hz servo signal untouched.
    pinMode(PIN_IN1, OUTPUT);
    pinMode(PIN_IN2, OUTPUT);
    pinMode(PIN_IN3, OUTPUT);
    pinMode(PIN_IN4, OUTPUT);
    digitalWrite(PIN_IN1, LOW);
    digitalWrite(PIN_IN2, HIGH);
    digitalWrite(PIN_IN3, LOW);
    digitalWrite(PIN_IN4, HIGH);

    ledcSetup(LEDC_CH_ENA, L298N_FREQ_HZ, PWM_RES_BITS);
    ledcAttachPin(PIN_EN_A, LEDC_CH_ENA);
    ledcSetup(LEDC_CH_ENB, L298N_FREQ_HZ, PWM_RES_BITS);
    ledcAttachPin(PIN_EN_B, LEDC_CH_ENB);
    setFlywheelDuty(0);

    // ── BTS7960 indexer setup (idle) ─────────────────────────────────────────
    pinMode(PIN_IDX_R_EN, OUTPUT);
    pinMode(PIN_IDX_L_EN, OUTPUT);
    digitalWrite(PIN_IDX_R_EN, HIGH);
    digitalWrite(PIN_IDX_L_EN, HIGH);
    ledcSetup(LEDC_CH_IDX, BTS_FREQ_HZ, PWM_RES_BITS);
    ledcAttachPin(PIN_IDX_RPWM, LEDC_CH_IDX);
    pinMode(PIN_IDX_LPWM, OUTPUT);
    digitalWrite(PIN_IDX_LPWM, LOW);
    ledcWrite(LEDC_CH_IDX, 0);

    // ── Servo (after motors, so ESP32Servo grabs a free LEDC channel) ───────
    servo.setPeriodHertz(50);
    if (servo.attach(PIN_SERVO, 500, 2500) < 0) {
        Serial.println("ERROR: servo.attach() failed.");
        while (true) delay(1000);
    }
    // Assume worst case (servo at center) and slew gently to the start angle.
    currentServoDeg = 90;
    servo.write(currentServoDeg);
    delay(500);
    slewServoTo(SWEEP_MIN_DEG);
    delay(200);
}

// ── Main loop: state machine drives the scan → aim → fire sequence ──────────
void loop() {
    switch (state) {

    case RobotState::SCAN:
        Serial.printf("\n=== SCAN (%d cycle(s)) ===\n", SCAN_CYCLES);
        for (int cycle = 0; cycle < SCAN_CYCLES; cycle++) {
            for (int deg = SWEEP_MIN_DEG; deg <= SWEEP_MAX_DEG; deg += SWEEP_STEP_DEG) {
                sampleAt(deg, bestAngle, bestDist);
            }
            for (int deg = SWEEP_MAX_DEG; deg >= SWEEP_MIN_DEG; deg -= SWEEP_STEP_DEG) {
                sampleAt(deg, bestAngle, bestDist);
            }
        }
        state = RobotState::AIM;
        break;

    case RobotState::AIM: {
        Serial.println("\n=== SCAN COMPLETE ===");
        int aimDeg;
        if (bestAngle < 0) {
            aimDeg = (SWEEP_MIN_DEG + SWEEP_MAX_DEG) / 2;
            Serial.println("WARNING: no valid LiDAR readings during scan.");
            Serial.printf("Minimum angle: (none)  →  rotating to midpoint %d° (straight ahead)\n", aimDeg);
        } else {
            aimDeg = bestAngle;
            Serial.printf("Minimum distance: %d cm at angle %d°\n", bestDist, bestAngle);
            Serial.printf("Rotating to %d°...\n", aimDeg);
        }
        slewServoTo(aimDeg - 2);
        delay(300);
        Serial.println("Aim complete.");
        state = RobotState::FIRE;
        break;
    }

    case RobotState::FIRE:
        Serial.println("Flywheels kick-start at 120/255.");
        setFlywheelDuty(FLY_KICK_DUTY);
        ledcWrite(LEDC_CH_IDX, 0);
        delay(FLY_KICK_MS);

        Serial.printf("Flywheels settled to %u/255. Spinning up...\n", FLY_DUTY);
        setFlywheelDuty(FLY_DUTY);
        delay(FLY_SETTLE_MS);

        Serial.printf("Indexer ON at duty=%u\n", IDX_DUTY);
        ledcWrite(LEDC_CH_IDX, IDX_DUTY);
        delay(IDX_SPIN_MS);

        stopAllMotors();
        Serial.println("All motors stopped. Done.");
        state = RobotState::DONE;
        break;

    case RobotState::DONE:
        break;
    }
}

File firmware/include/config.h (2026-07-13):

#pragma once

// ─── I2C ─────────────────────────────────────────────────────────────────────
#define PIN_SDA             21   // TF-Luna SDA
#define PIN_SCL             22   // TF-Luna SCL
#define TFLUNA_I2C_ADDR     0x10

// ─── BTS7960 H-Bridge (Flywheel motors – combined channel) ───────────────────
// NOTE: Both flywheel motors share one BTS7960 channel (known constraint).
#define PIN_FLY_RPWM        18
#define PIN_FLY_LPWM        19
#define PIN_FLY_R_EN        25
#define PIN_FLY_L_EN        26

// LEDC channels for BTS7960 PWM
#define LEDC_CH_RPWM        0
#define LEDC_CH_LPWM        1
#define LEDC_PWM_FREQ_HZ    20000  // 20 kHz – above audible range
#define LEDC_PWM_RES_BITS   8      // 0–255 duty cycle

// ─── MG995 Servo (Turret rotation) ───────────────────────────────────────────
#define PIN_SERVO           4

// ─── JGA25-371 Gearmotor + Quadrature Encoder (planned) ──────────────────────
// Motor driver (generic interface): PWM + DIR
// Encoder: A/B channels
//
// Chosen to avoid pins currently used by tests and common ESP32 bootstraps.
// - GPIO32/33 are input-only (good for encoder).
// - GPIO16/17 are general-purpose outputs (good for driver PWM/DIR).
#define PIN_GEAR_PWM        16
#define PIN_GEAR_DIR        17
#define PIN_GEAR_ENC_A      32
#define PIN_GEAR_ENC_B      33

// ─── Hall Effect Sensors (Flywheel RPM feedback, input-only pins) ─────────────
#define PIN_HALL_1          13   // Flywheel motor 1
#define PIN_HALL_2          14   // Flywheel motor 2

// ─── Limit Switches (Turret end-stops for homing) ────────────────────────────
#define PIN_LIMIT_CW        4   // Clockwise travel limit
#define PIN_LIMIT_CCW       5   // Counter-clockwise travel limit

// ─── IR Beam (Ball-in-chamber sensor, input-only) ────────────────────────────
#define PIN_IR_BEAM         27   // HIGH = beam unbroken (no ball); LOW = ball present

// ─── Feeder motor (DRV8833, 2nd-order part – pins TBD when hardware arrives) ──
#define PIN_FEED_IN1        -1   // Placeholder
#define PIN_FEED_IN2        -1   // Placeholder

// ─── User button ─────────────────────────────────────────────────────────────
#define PIN_BUTTON          0    // GPIO0 / BOOT button on DevKit (active-low)

// ─── Turret geometry ─────────────────────────────────────────────────────────
#define TURRET_HOME_DEG     90.0f  // Straight-ahead position
#define TURRET_MIN_DEG       0.0f
#define TURRET_MAX_DEG     180.0f

// ─── Scan parameters ─────────────────────────────────────────────────────────
#define SCAN_START_DEG      30.0f  // Left limit of scan arc
#define SCAN_END_DEG       150.0f  // Right limit of scan arc
#define SCAN_STEP_DEG        2.0f  // Angular resolution
#define SCAN_DWELL_MS          80  // ms to wait at each step before reading

// Cup detection: a return shorter than (background − DELTA) is a cup candidate
#define CUP_DIST_MIN_MM      300   // Minimum plausible cup distance
#define CUP_DIST_MAX_MM     2400   // Table length; farther is background
#define CUP_DETECT_DELTA_MM   80   // How much shorter than background = cup

// ─── Ballistics ──────────────────────────────────────────────────────────────
#define LAUNCH_ANGLE_DEG    55.0f   // Fixed vertical launch angle
#define LAUNCHER_HEIGHT_M   0.20f   // Launcher exit height above table surface
#define CUP_RIM_HEIGHT_M    0.12f   // Cup rim height above table surface
// Height difference seen by projectile: launcher is above cup rim
#define DELTA_HEIGHT_M      (LAUNCHER_HEIGHT_M - CUP_RIM_HEIGHT_M)

// Flywheel: ball exit velocity ≈ flywheel rim speed (nerf-style compression launch)
#define FLYWHEEL_RADIUS_M   0.030f  // Wheel radius in metres
// RPM → ball speed:  v = ω·r = (RPM·2π/60)·r
// Rearranged:        RPM = v·60 / (2π·r)

// Closed-loop RPM: the hall sensor produces one pulse per magnet pole per rev.
// Adjust HALL_POLES to match your motor's magnet count.
#define HALL_POLES           2      // Pulses per revolution
#define RPM_MEASURE_WINDOW_MS 200   // Integration window for RPM measurement
#define RPM_TOLERANCE        150    // ±RPM considered "at setpoint"

// ─── Timing ──────────────────────────────────────────────────────────────────
#define SPINUP_TIMEOUT_MS   5000   // Abort spinup if RPM not reached in this time
#define FIRE_PULSE_MS        600   // Duration feeder motor runs to push one ball
#define COOLDOWN_MS         1500   // Wait after shot before next cycle

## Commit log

2026-07-14 Add Final_CAD_Assembly.step file
    [Final_CAD_Assembly.step]
2026-07-14 Update link format for static CAD file in README
2026-10-29 Add demo video and LiDAR scan GIF to top of README
